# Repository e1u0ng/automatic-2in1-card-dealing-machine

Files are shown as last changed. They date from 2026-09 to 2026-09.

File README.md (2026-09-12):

# 🃏 Automated ESP32 Card Shuffler & Launcher

An ESP32-powered machine that shuffles and passes cards to players with an interactive menu screen for customized game settings. 

## 🔄 V1 Assembly Changes (9/11/26)
* **Improved Shuffler Performance:** 
  * Increased deck space to prevent overflowing cards going near spinning wheels
  * Covered more gap in the inner walls to prevent lodged cards
* **Redesigned Dispenser:** 
  * Added an angled ramp in the deck compartment to guarantee contact with the wheels (aimed to combat inconsistency with bent cards)
  * Switched to compound gear train for compactness and its gear ratio from 1:6.5 to 1:10 to make up for smaller wheel diameter
  * Switched to 32 mm diameter gecko wheels for compactness
* **Code Layout Redesign:** 
  * Implemented header files and source files for each subsystem (dispenser, shuffler, turret, menu) containing initialization and action functions
  * Used a separate command system file to translate inputs (button encoders) into outputs from the shuffler, dispenser, turret, and menu screen 
  * Utilized the FreeRTOS task system to run multiple tasks at the same time

## 🚀 Next Steps
* **Github Files:**
  * Upload current bill of materials for V1 (BOM)
  * Update specifications checklist for V1
* **Power Management:**
  * Assemble the 12.6V 3S Li-ion battery pack with integrated BMS protection.
  * Wire an SPDT charging/main power selector switch to safely isolate the load during recharges.
  * Implement an ESP32 ADC resistor divider circuit and software-based low-voltage shutdown routine before BMS cutoff.
* **Turret Redesign:**
  * Switch to a smaller brushed DC motor and separate absolute magnetic encoder
  * Refine ESP-IDF PID loop control for new turret setup and implement exact player-angle targeting using an absolute encoder
* **PCB Design:**
  * Design PCB to hold the ESP32 microcontroller, shutdown circuit, and power lines for compactness
* **Sensors Implementations:**
  * Integrate IR sensors for directional card delivery detection and optional distance sensors for adaptive shuffle timing.
* **Enclosure Design:**
  * Use Fusion360 to design a container to hold the subsystems together for a finished look

## 📂 Repository Structure
* `docs/` — Design sketches, calculations, and proof-of-concept testing logs.
* `hardware/` — Circuit diagrams, power schematics, and 3D STL/STEP models.
* `main/` — ESP32 C++ source code and all test codes

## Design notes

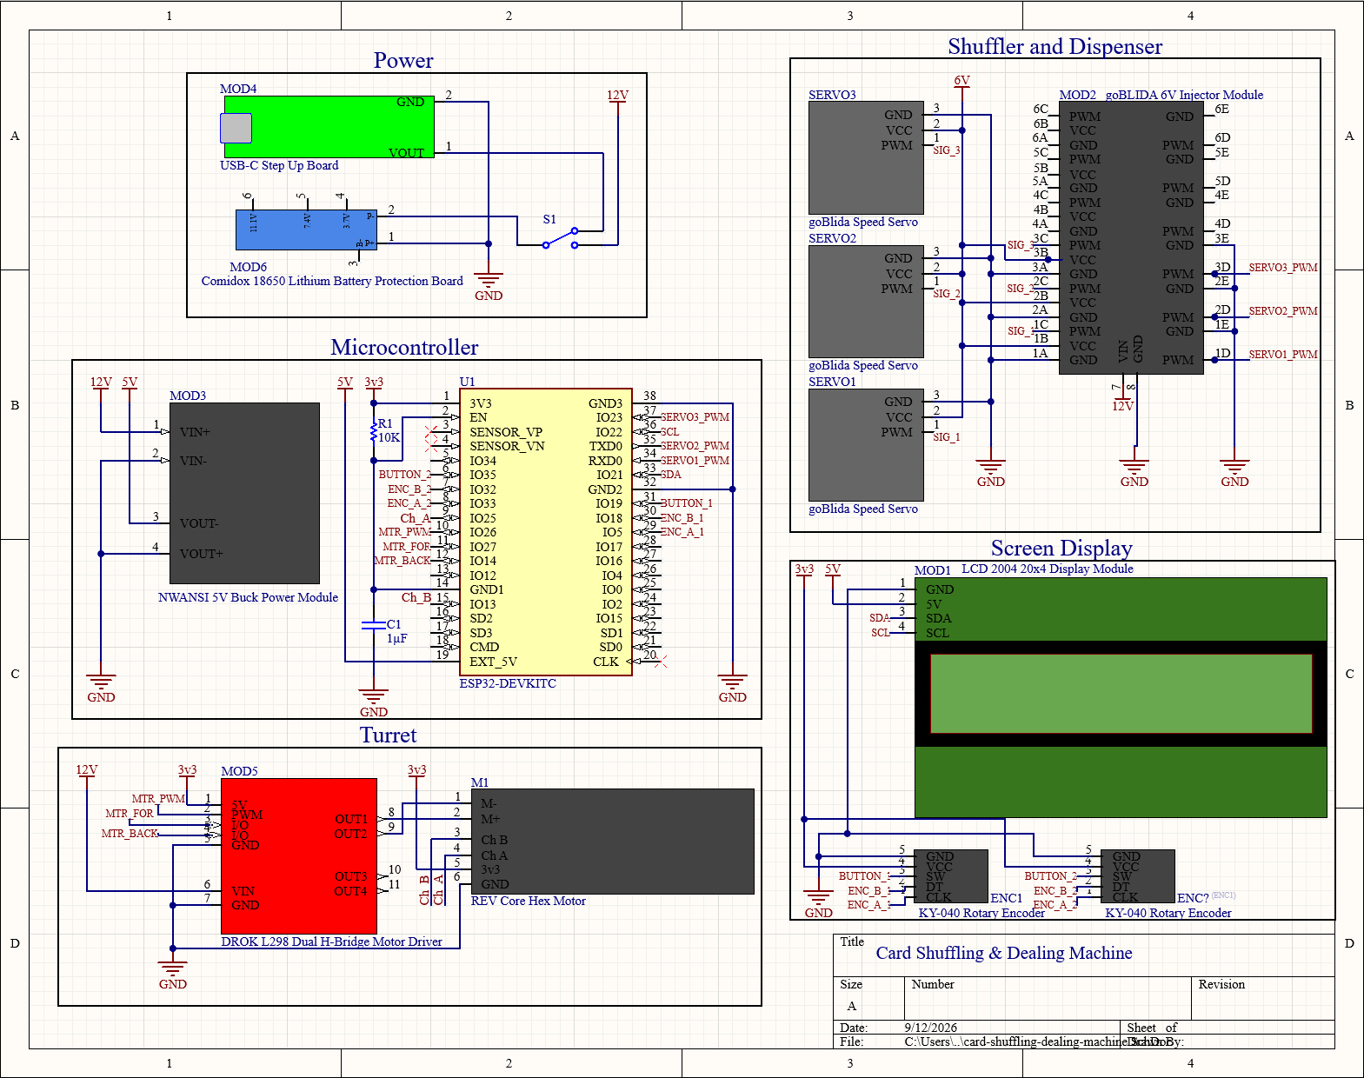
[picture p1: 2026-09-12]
hardware/schematics/card-shuffling-dealing-machine-schematic.png

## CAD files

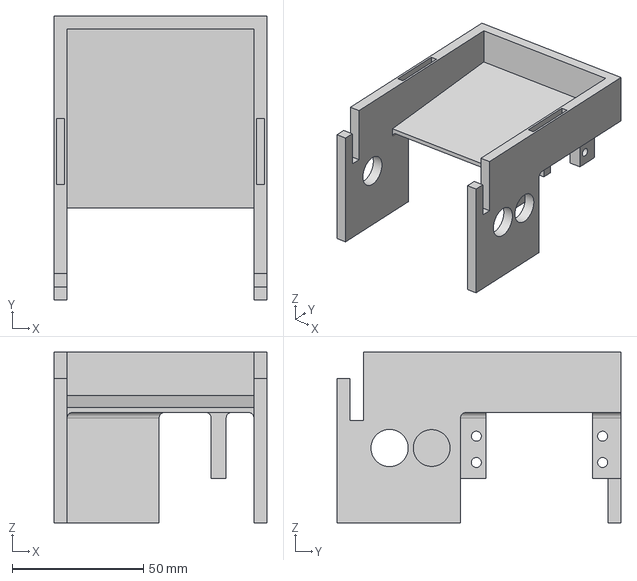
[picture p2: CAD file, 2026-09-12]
hardware/3d_models/step/dispenser/card-dispenser-chassis.step
81.0 x 108.0 x 65.0 mm

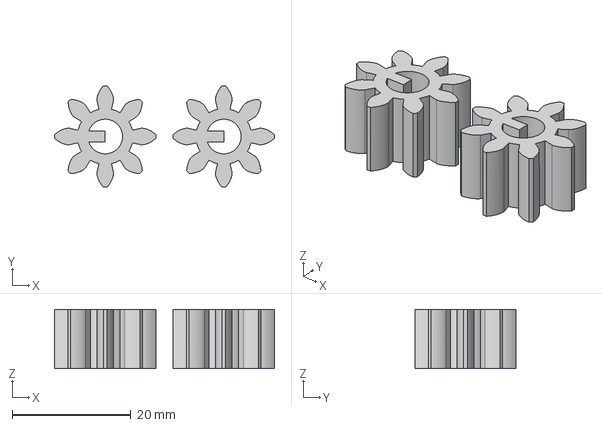
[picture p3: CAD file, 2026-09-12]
hardware/3d_models/step/shuffler/card-shuffler-driven-gears.step
37.1 x 17.1 x 10.0 mm

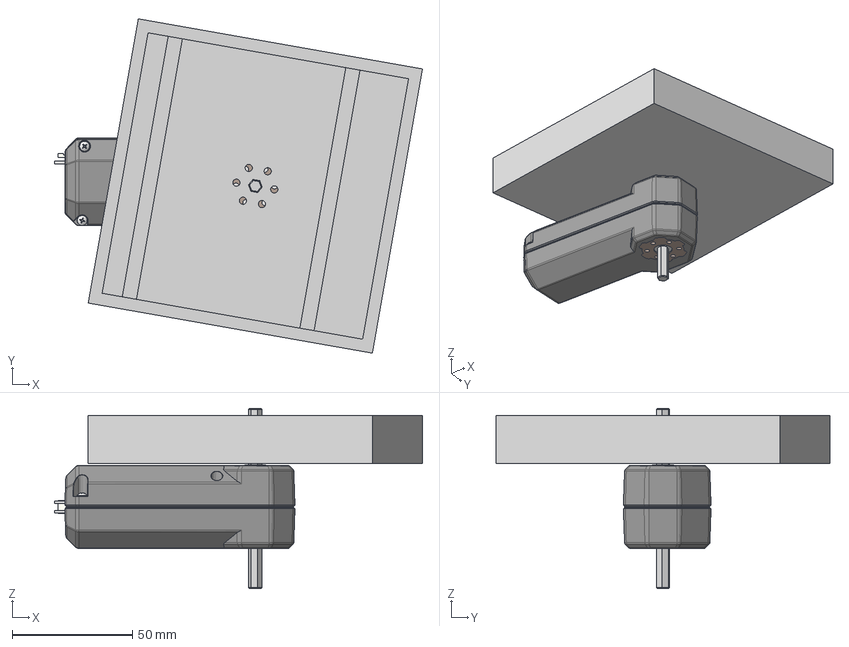
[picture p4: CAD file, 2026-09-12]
hardware/3d_models/step/turret/card-turret.step
153.0 x 139.0 x 75.0 mm

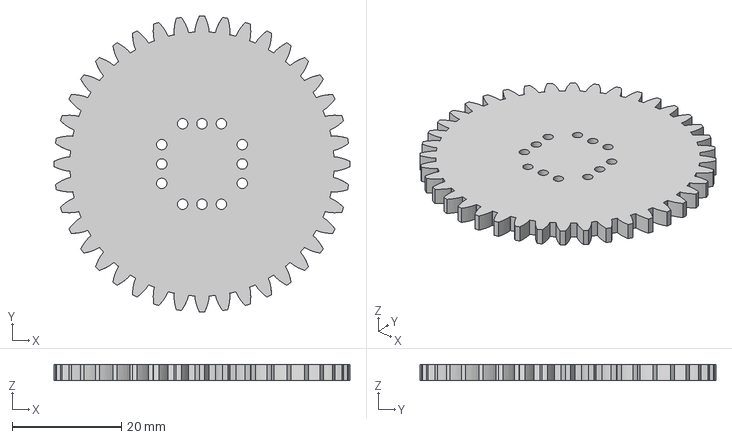
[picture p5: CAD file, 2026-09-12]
hardware/3d_models/step/dispenser/dispenser-driver-gear.step
54.2 x 54.2 x 3.00 mm

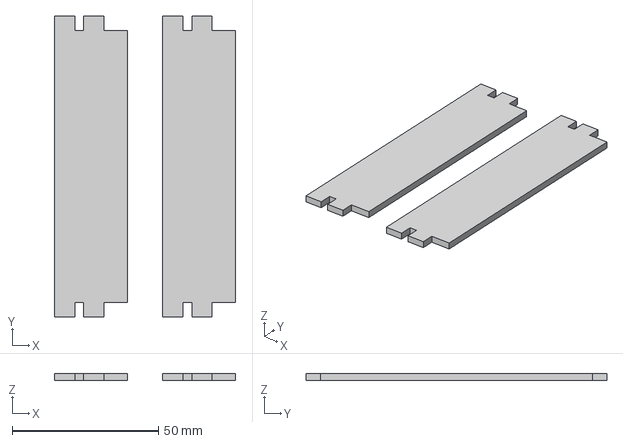
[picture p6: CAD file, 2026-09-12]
hardware/3d_models/step/shuffler/card-shuffler-platforms.step
62.0 x 103.0 x 2.50 mm

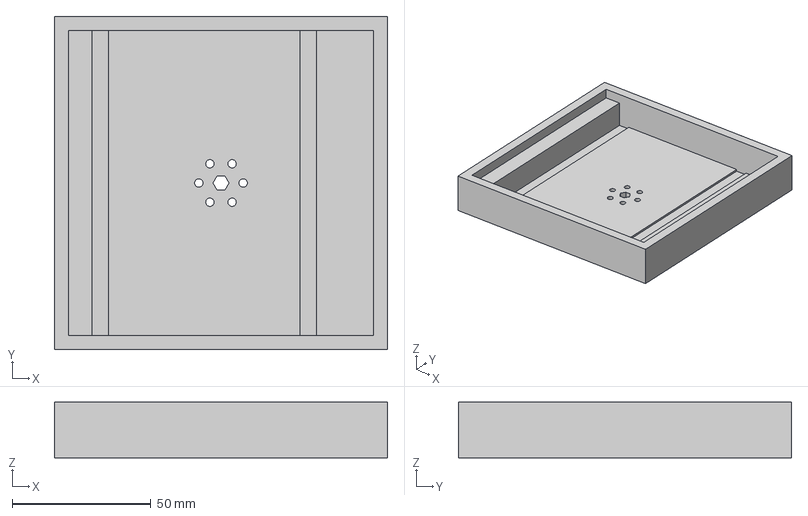
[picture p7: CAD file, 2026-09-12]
hardware/3d_models/step/turret/card-turret-platform.step
120.0 x 120.0 x 20.0 mm

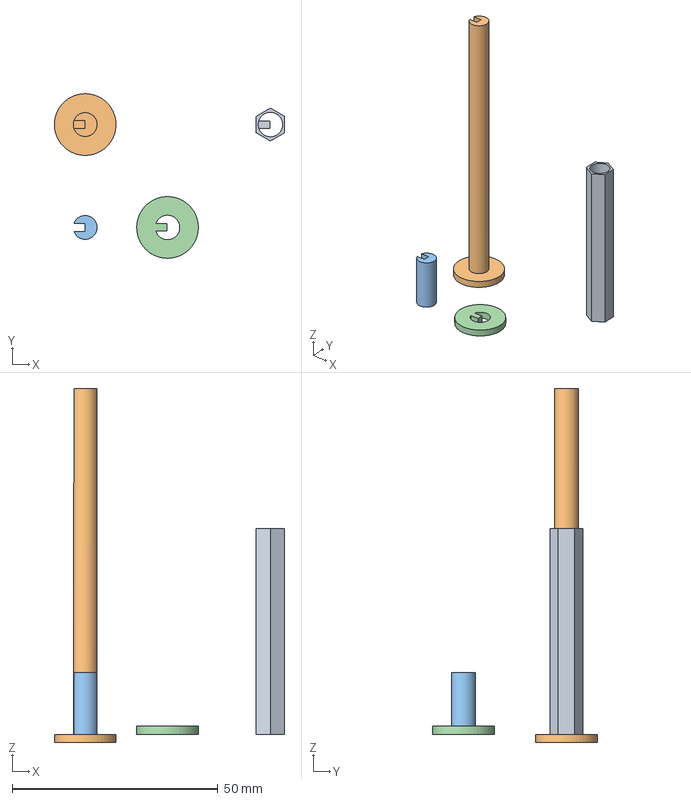
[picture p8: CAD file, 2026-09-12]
hardware/3d_models/step/dispenser/card-dispenser-shaft.step
56.0 x 40.0 x 86.0 mm

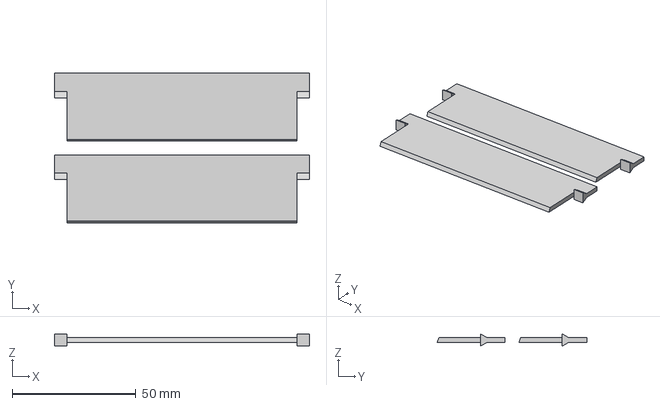
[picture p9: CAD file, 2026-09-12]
hardware/3d_models/step/shuffler/card-shuffler-gates.step
103.0 x 60.5 x 5.00 mm

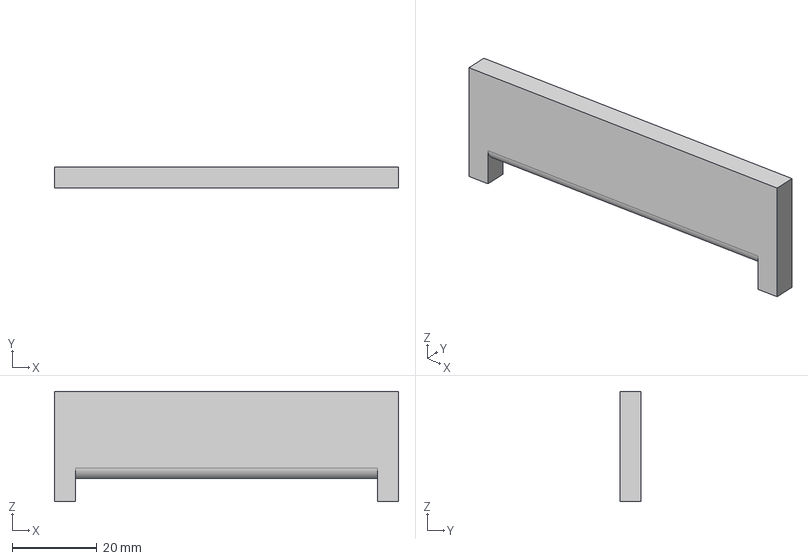
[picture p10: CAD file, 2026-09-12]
hardware/3d_models/step/dispenser/dispenser-gate.step
81.0 x 5.00 x 26.0 mm

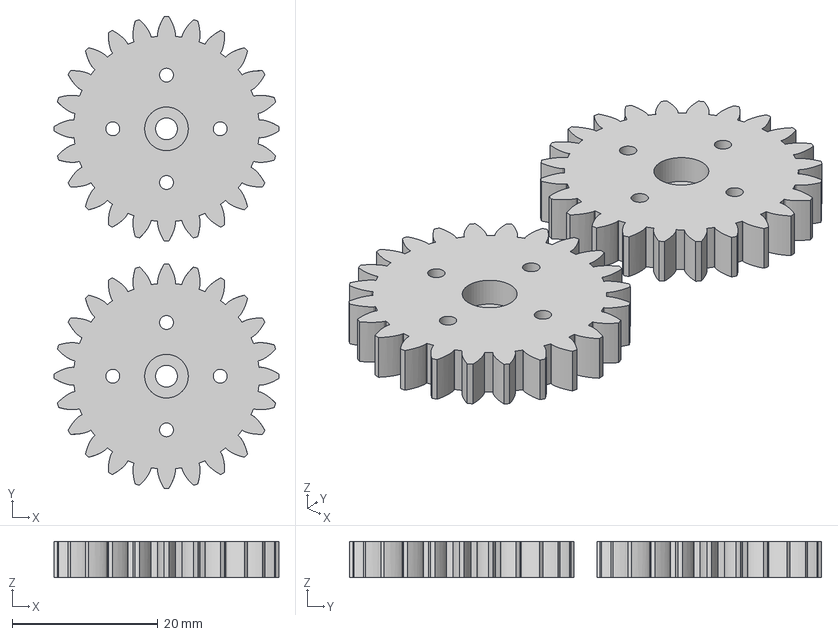
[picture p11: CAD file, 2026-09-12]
hardware/3d_models/step/shuffler/card-shuffler-driver-gears.step
30.9 x 64.9 x 5.00 mm

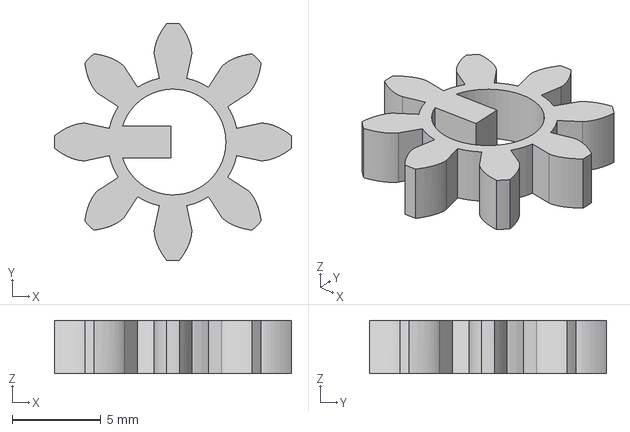
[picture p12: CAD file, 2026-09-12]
hardware/3d_models/step/dispenser/dispenser-driven-gear.step
13.3 x 13.3 x 3.00 mm

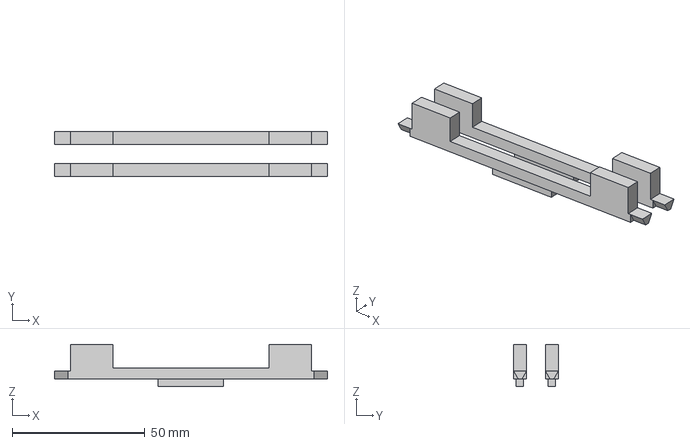
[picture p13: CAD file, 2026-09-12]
hardware/3d_models/step/shuffler/card-shuffler-inner-walls.step
103.0 x 17.0 x 16.0 mm

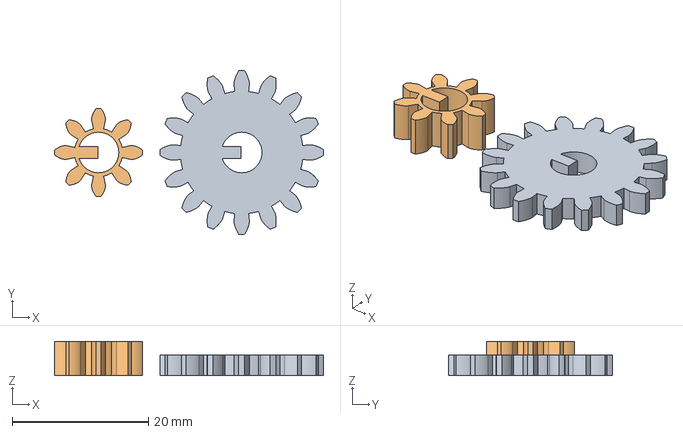
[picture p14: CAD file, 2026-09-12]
hardware/3d_models/step/dispenser/card-dispenser-middle-gears.step
39.5 x 24.0 x 5.00 mm

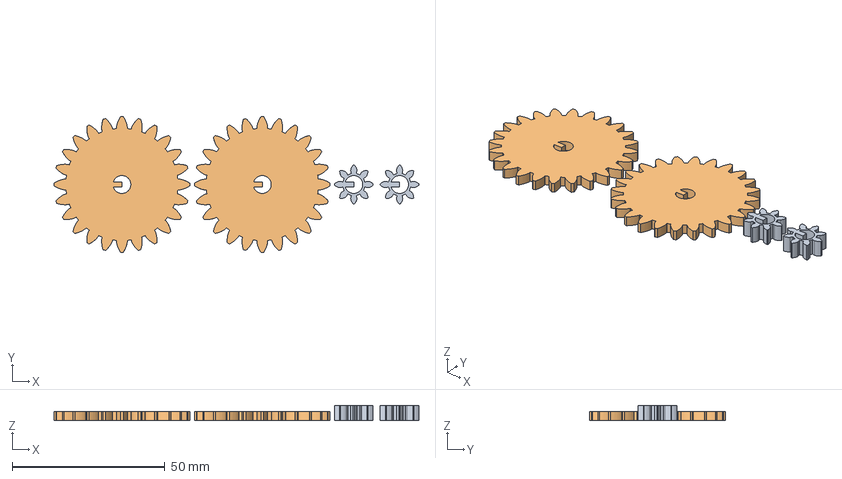
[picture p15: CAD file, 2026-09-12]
hardware/3d_models/step/shuffler/card-shuffler-middle-gears.step
119.6 x 44.5 x 5.00 mm

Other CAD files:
hardware/3d_models/step/dispenser/card-dispenser.step
hardware/3d_models/step/shuffler/card-shuffler-side-plates.step
hardware/3d_models/step/shuffler/card-shuffler-wheels-and-shaft.step
hardware/3d_models/step/shuffler/card-shuffler.step
hardware/3d_models/source/dispenser/card-dispenser.f3z
hardware/3d_models/source/shuffler/card-shuffler.f3z
hardware/3d_models/source/turret/card-turret.f3z
hardware/3d_models/stl/dispenser/card-dispenser-chassis.stl
hardware/3d_models/stl/dispenser/card-dispenser-middle-gears.stl
hardware/3d_models/stl/dispenser/card-dispenser-shaft.stl
hardware/3d_models/stl/dispenser/dispenser-driven-gear.stl
hardware/3d_models/stl/dispenser/dispenser-driver-gear.stl
hardware/3d_models/stl/dispenser/dispenser-gate.stl
hardware/3d_models/stl/shuffler/card-shuffler-driven-gears.stl
hardware/3d_models/stl/shuffler/card-shuffler-driver-gears.stl
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

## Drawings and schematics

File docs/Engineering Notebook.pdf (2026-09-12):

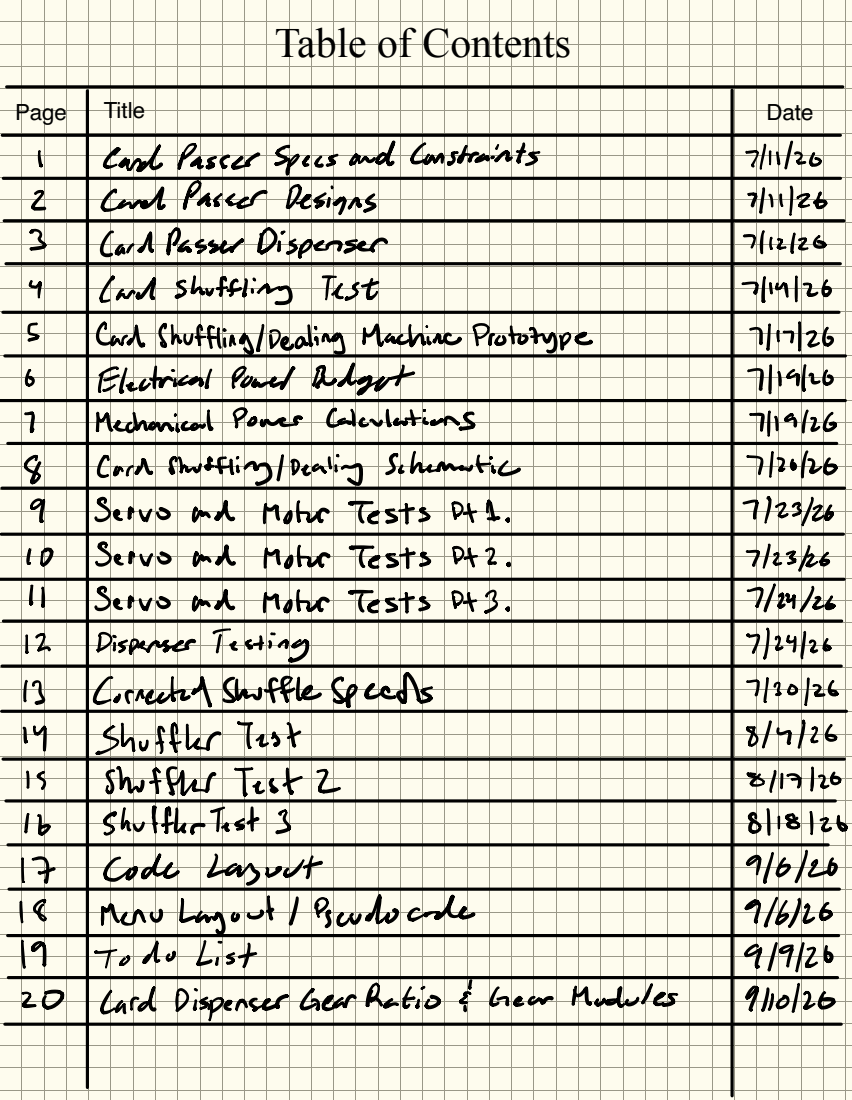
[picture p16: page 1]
Page; Title; Date

Table of Contents

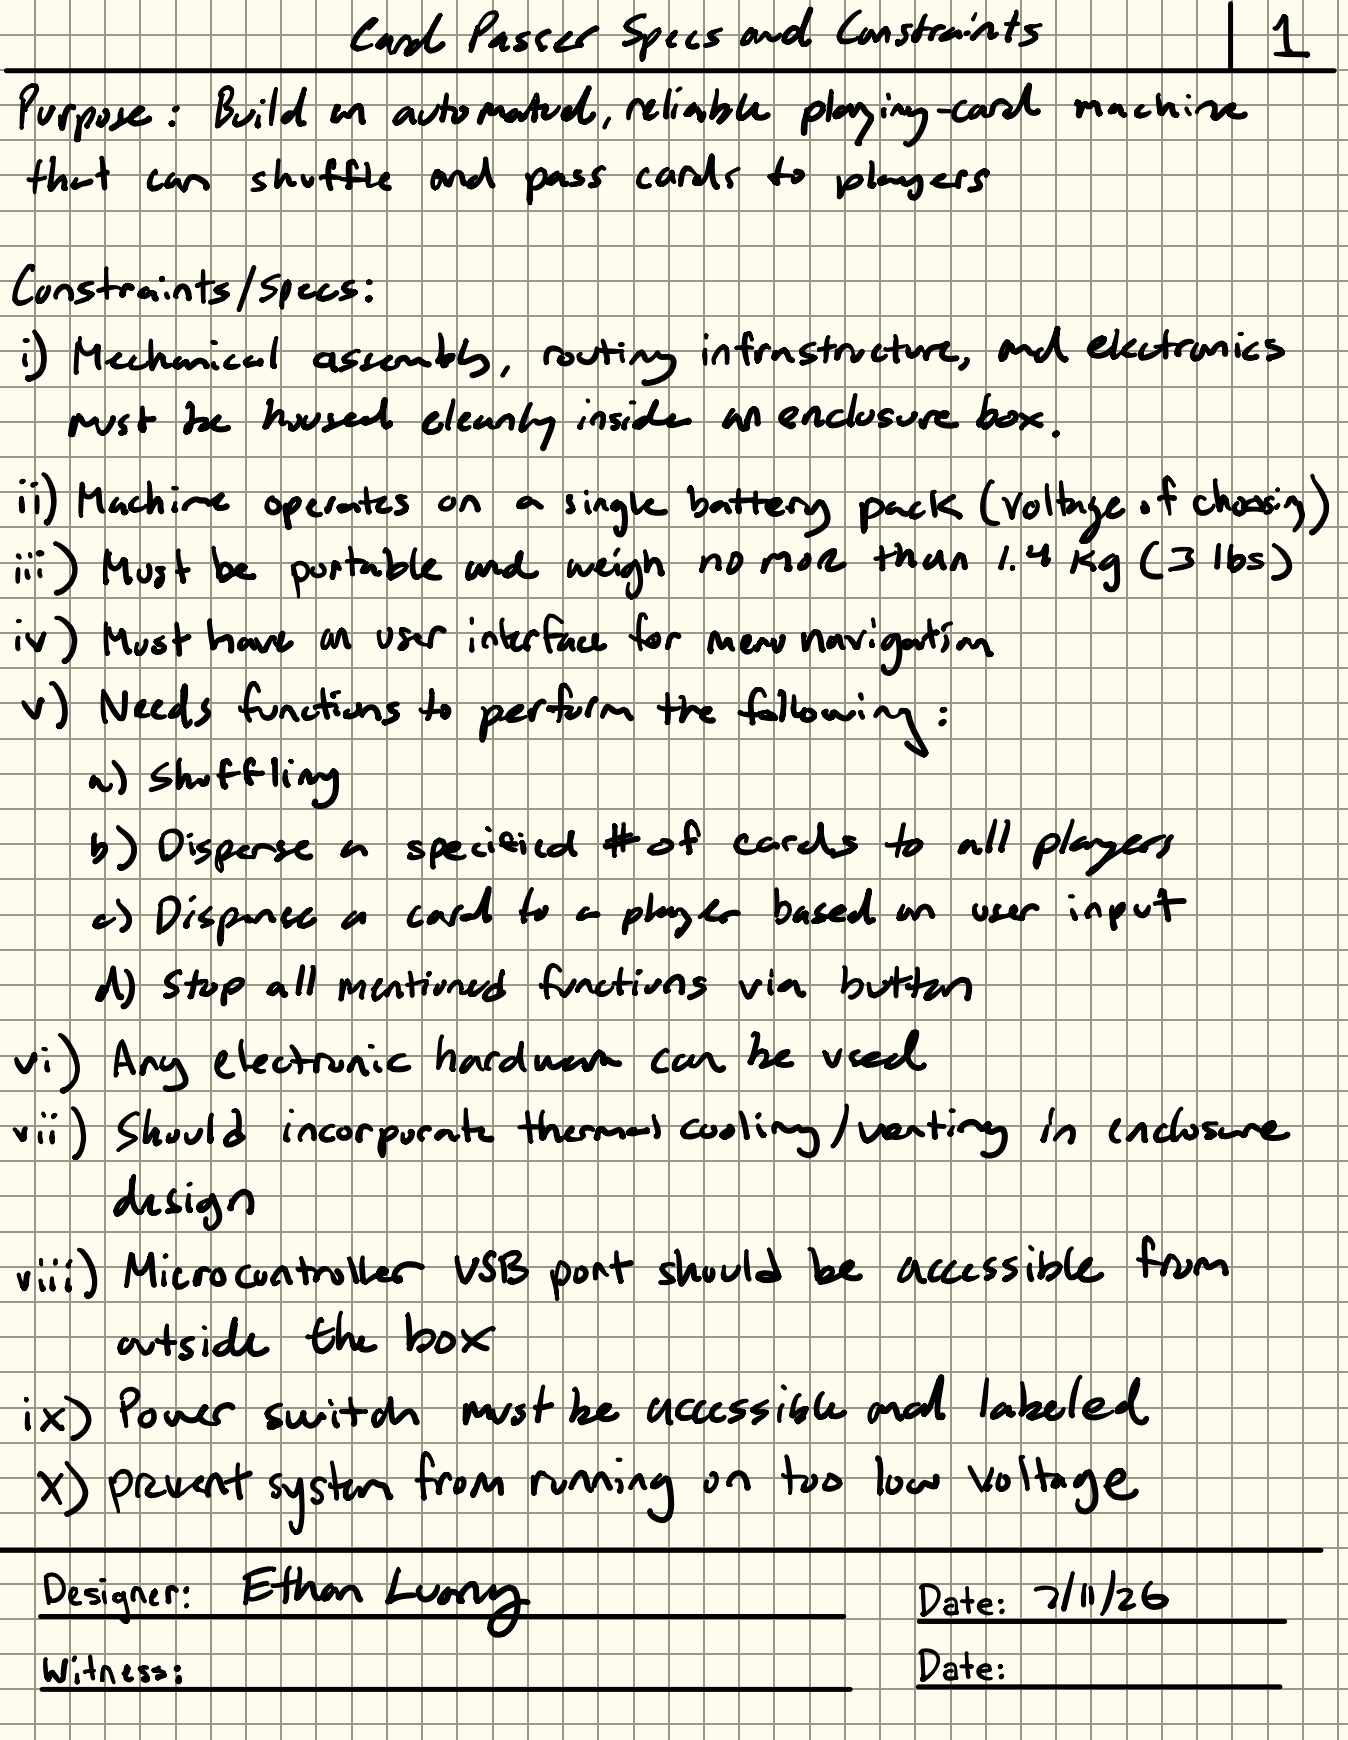
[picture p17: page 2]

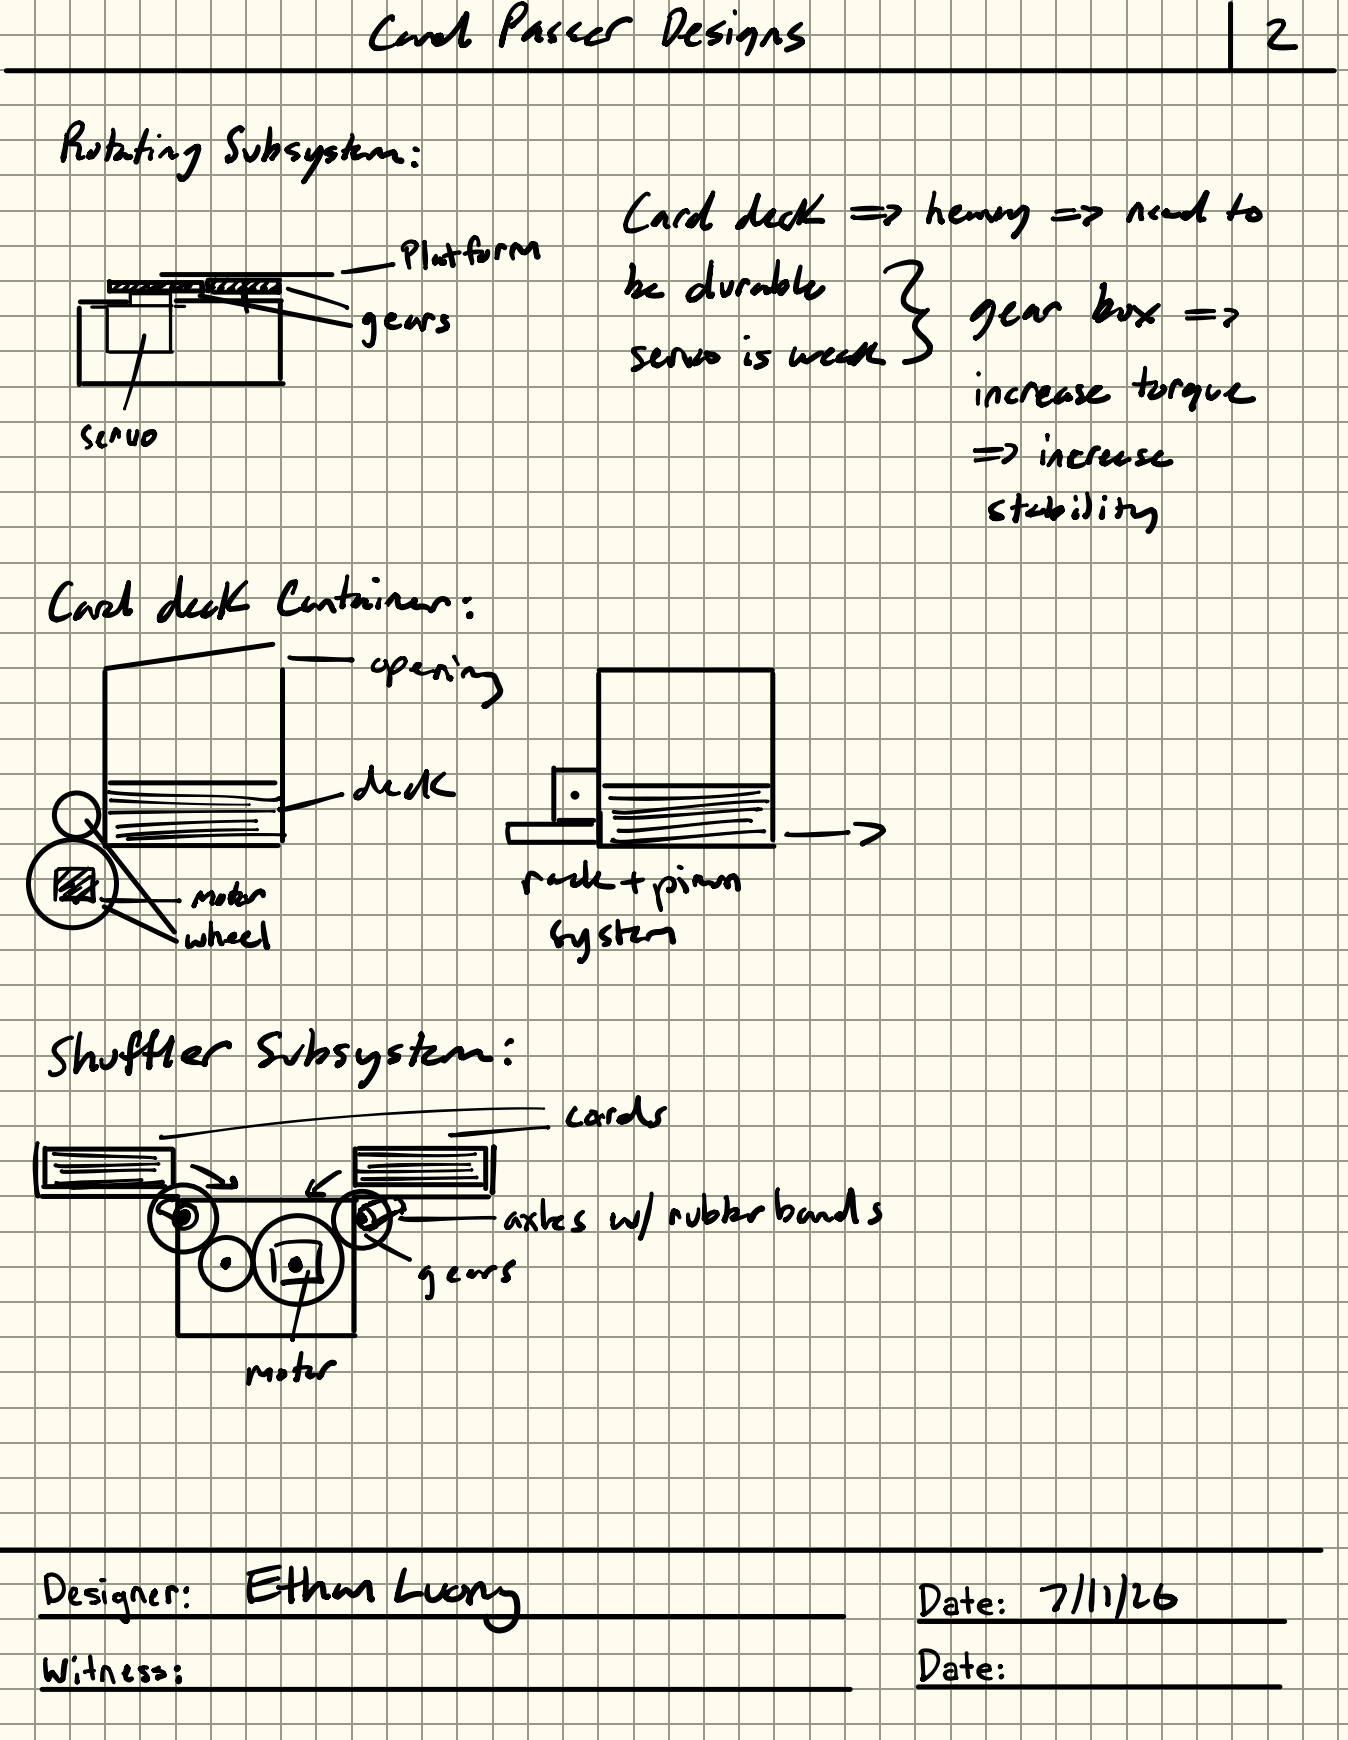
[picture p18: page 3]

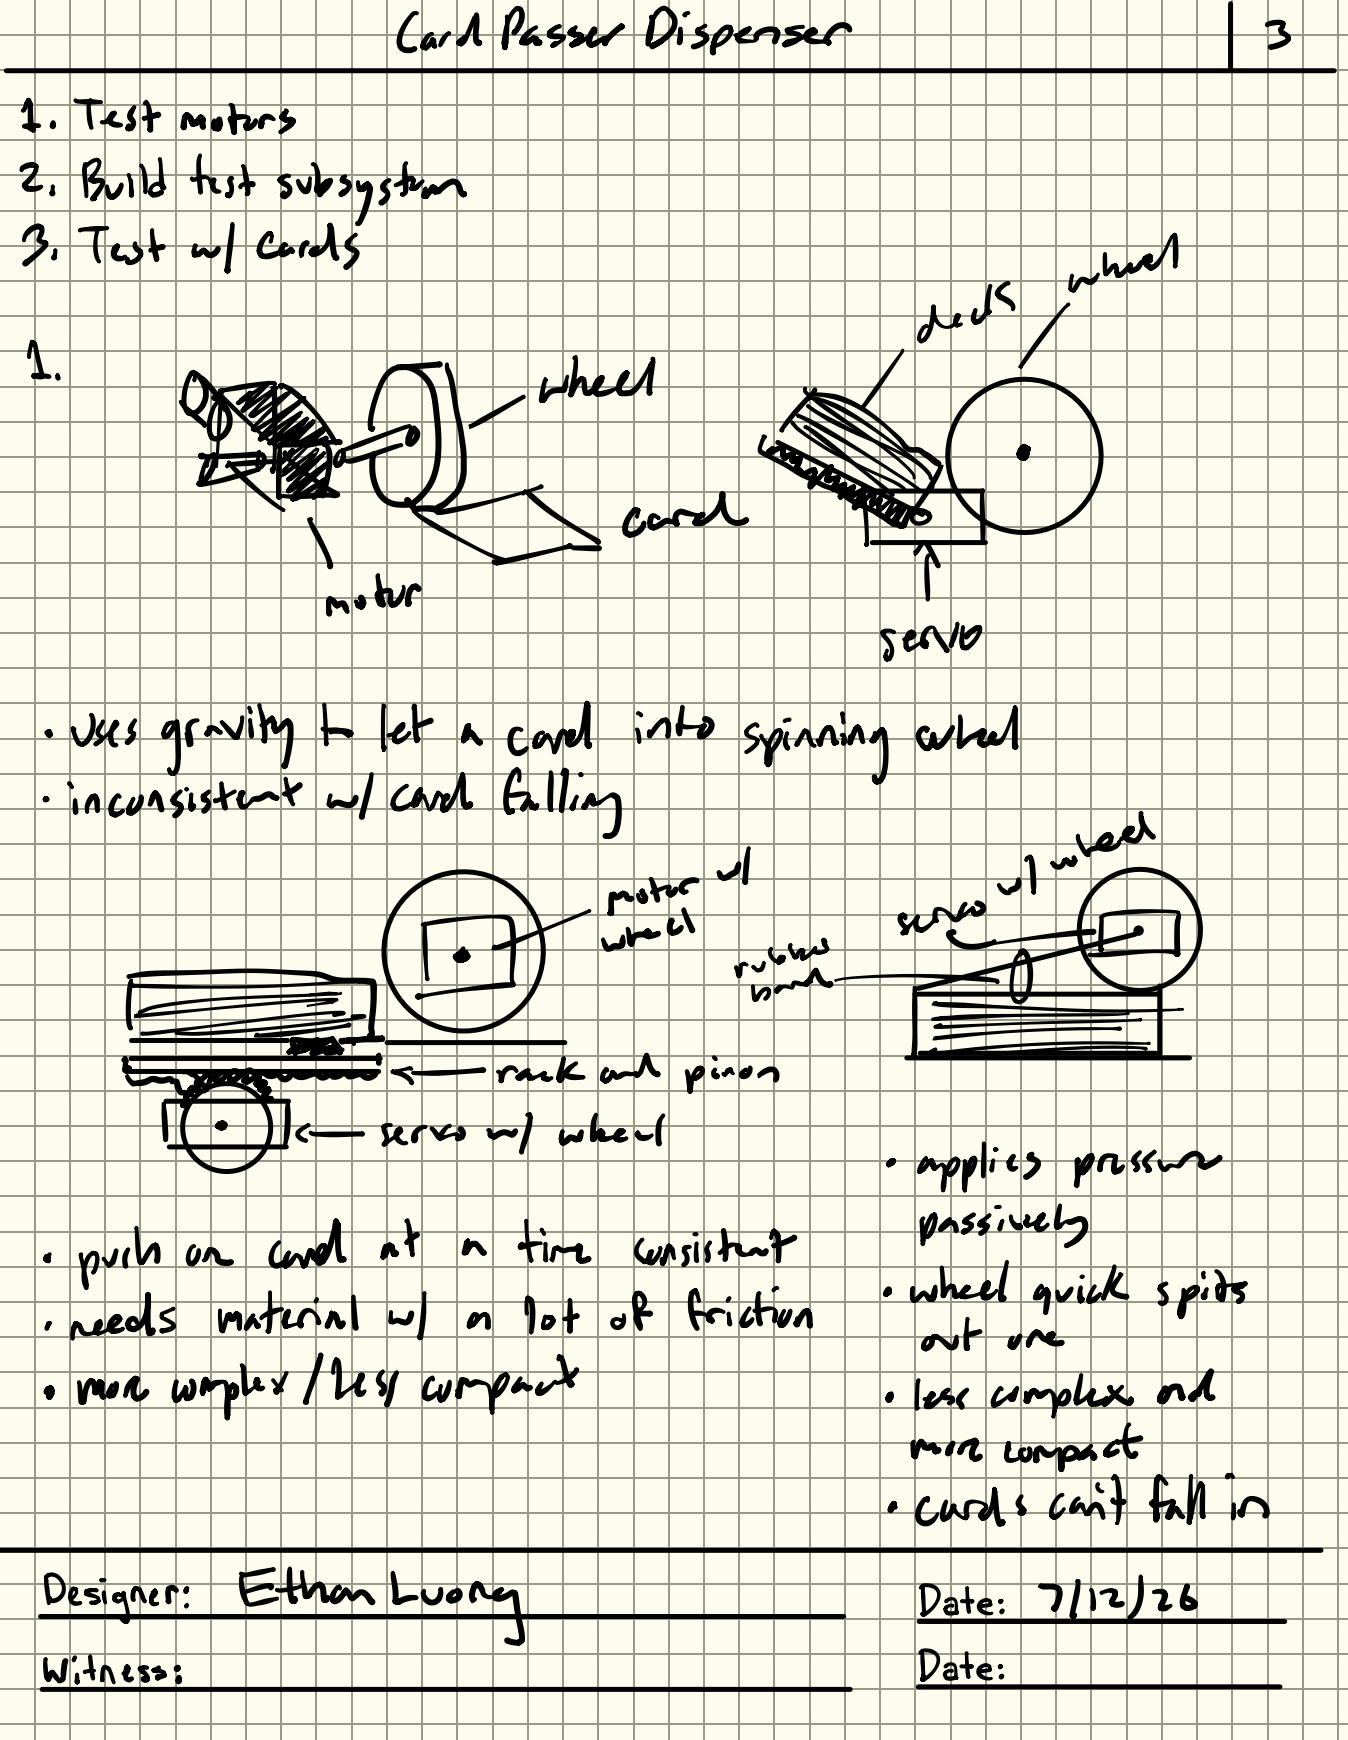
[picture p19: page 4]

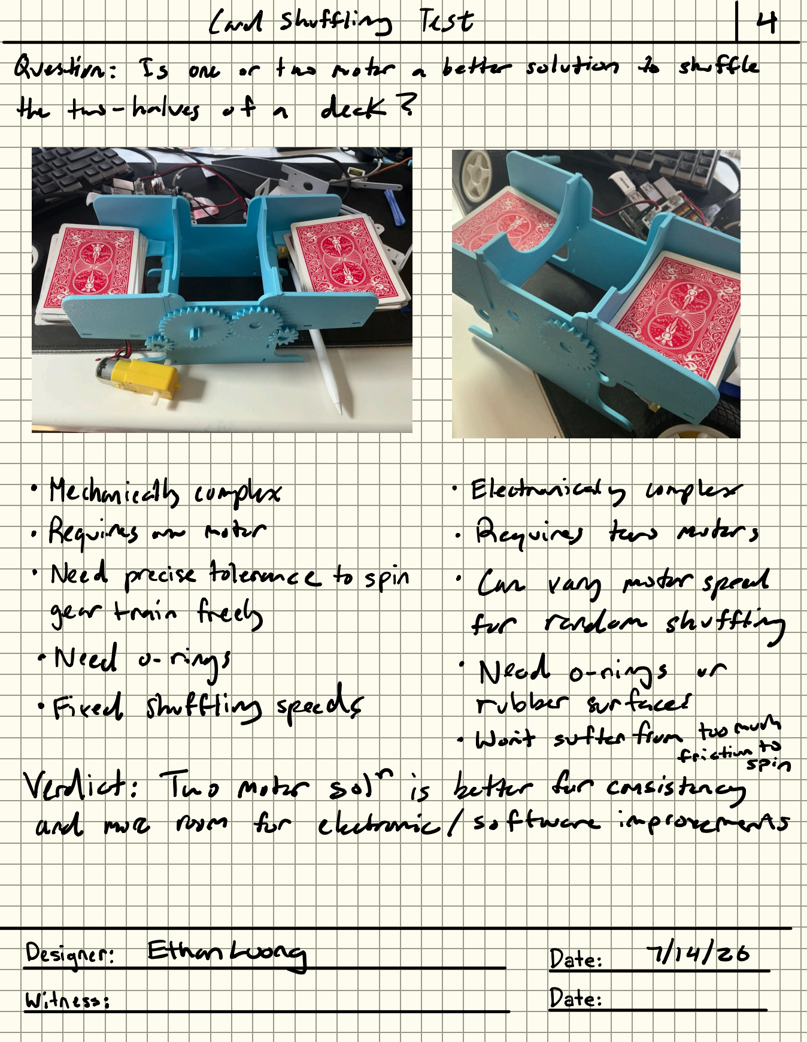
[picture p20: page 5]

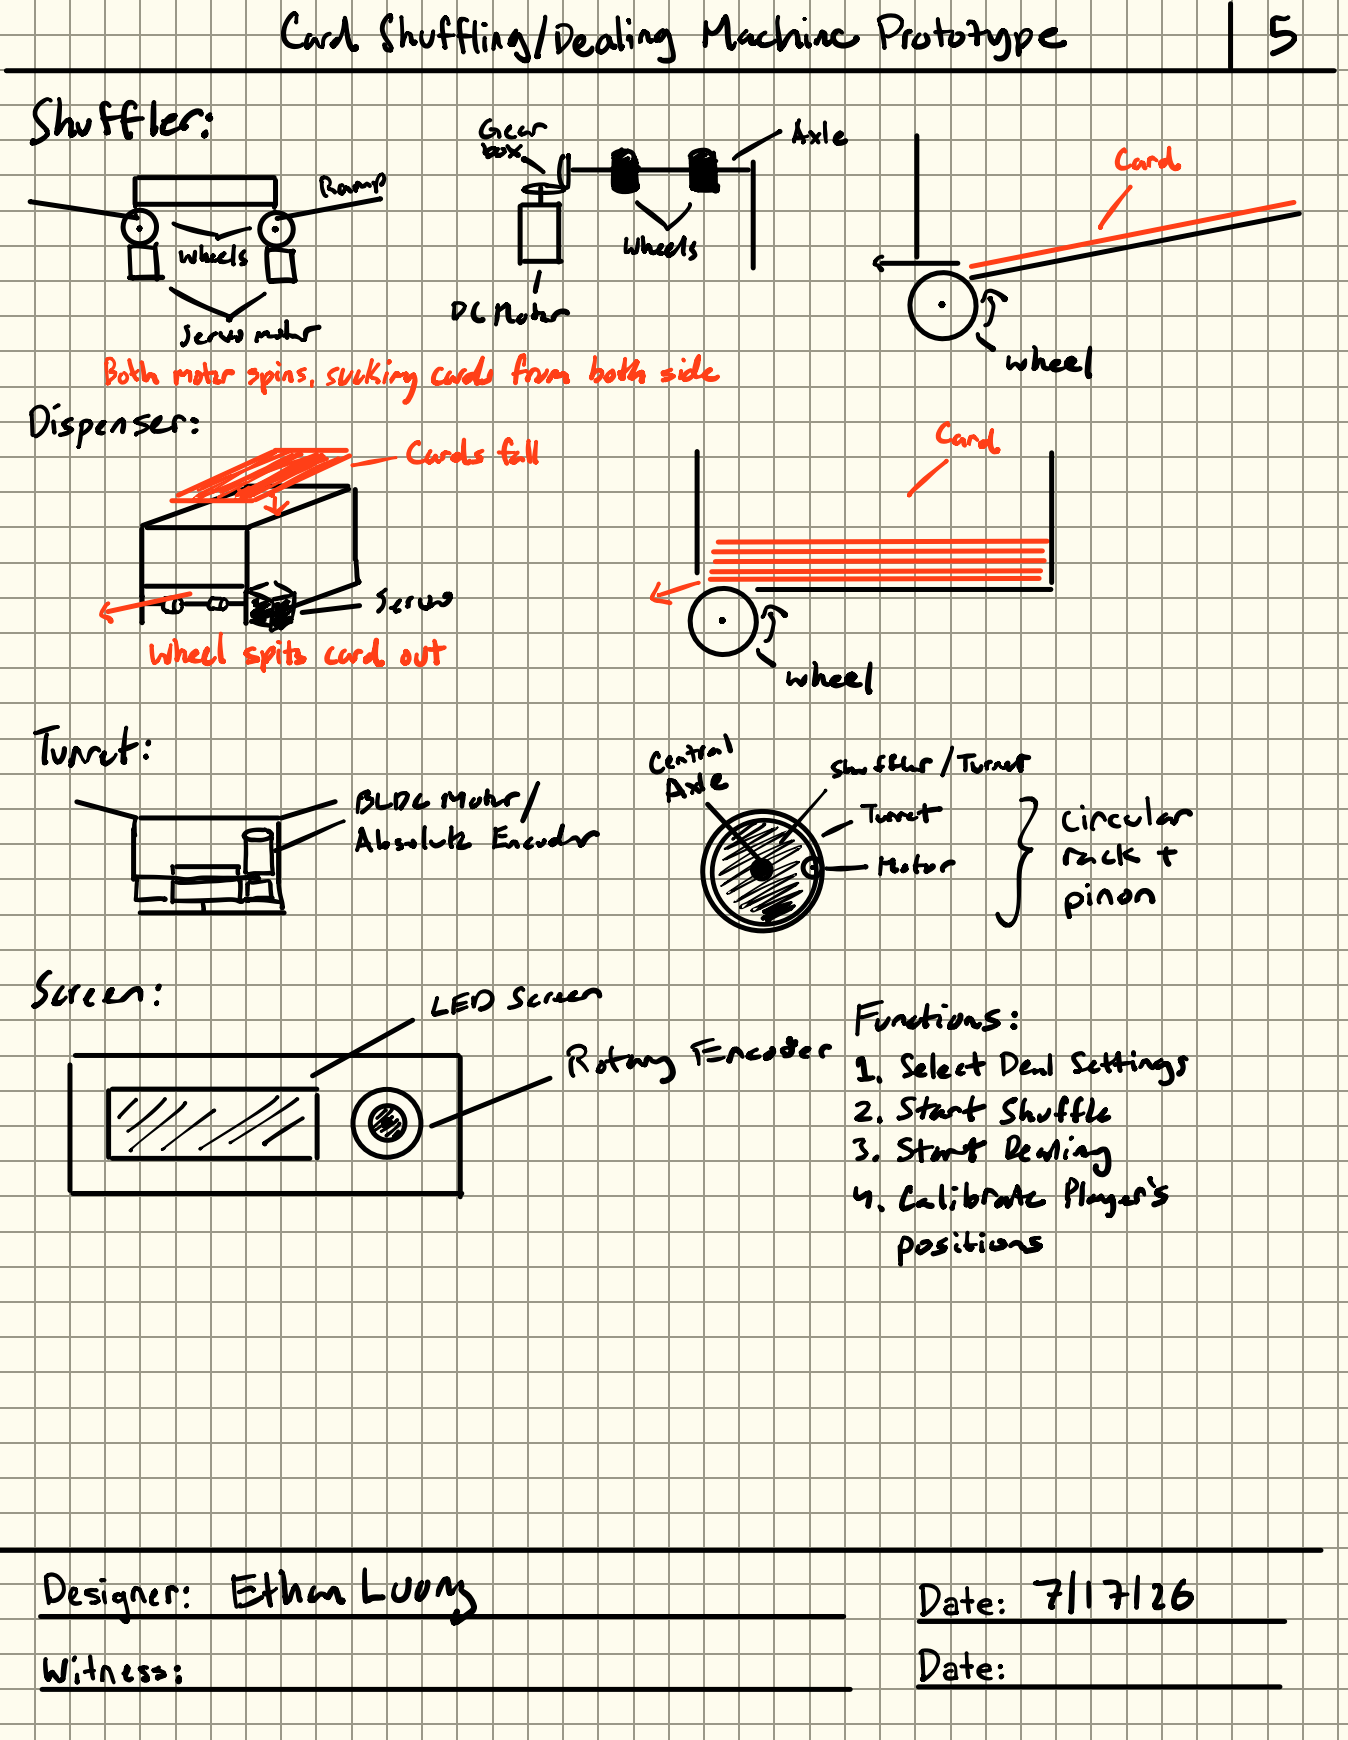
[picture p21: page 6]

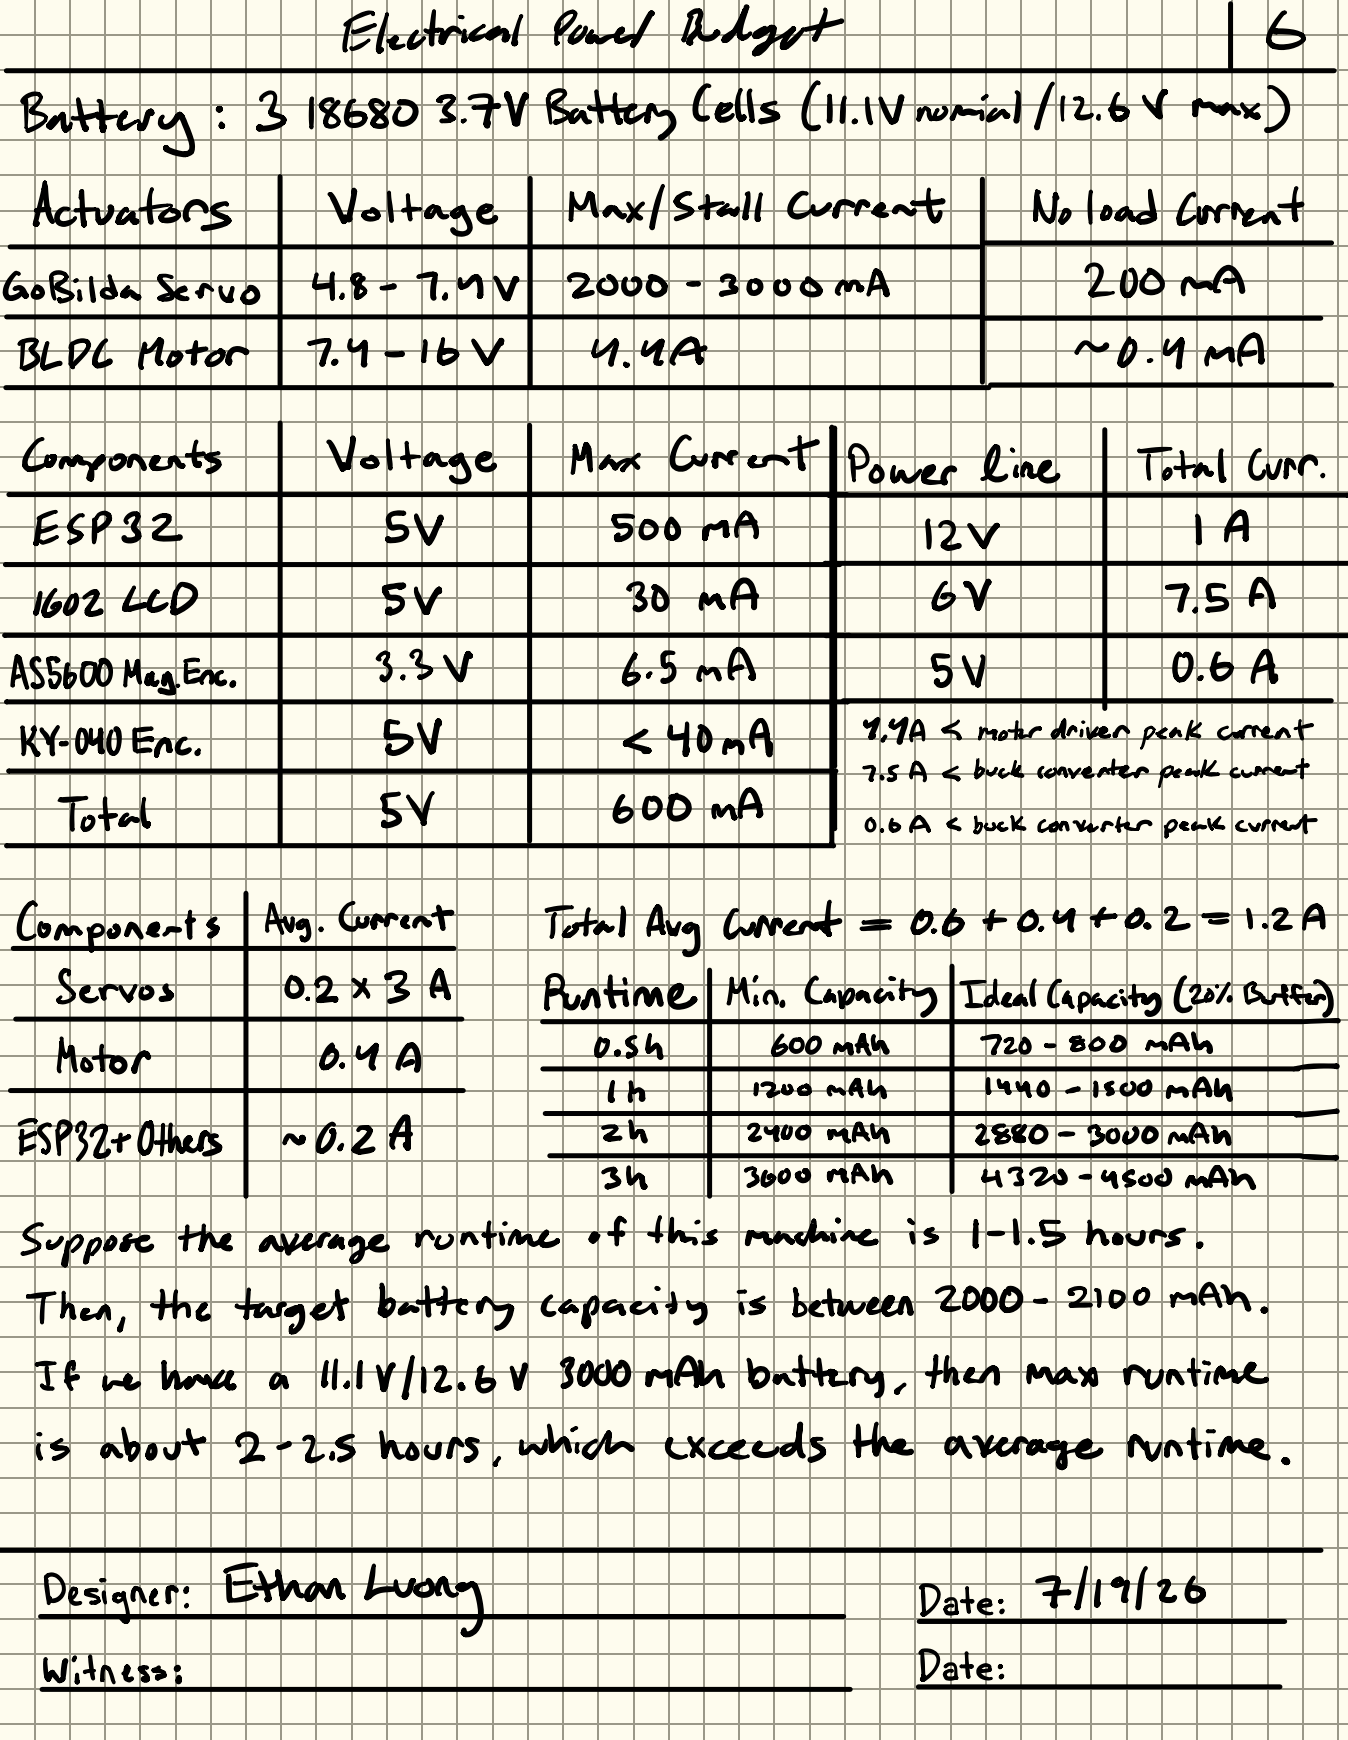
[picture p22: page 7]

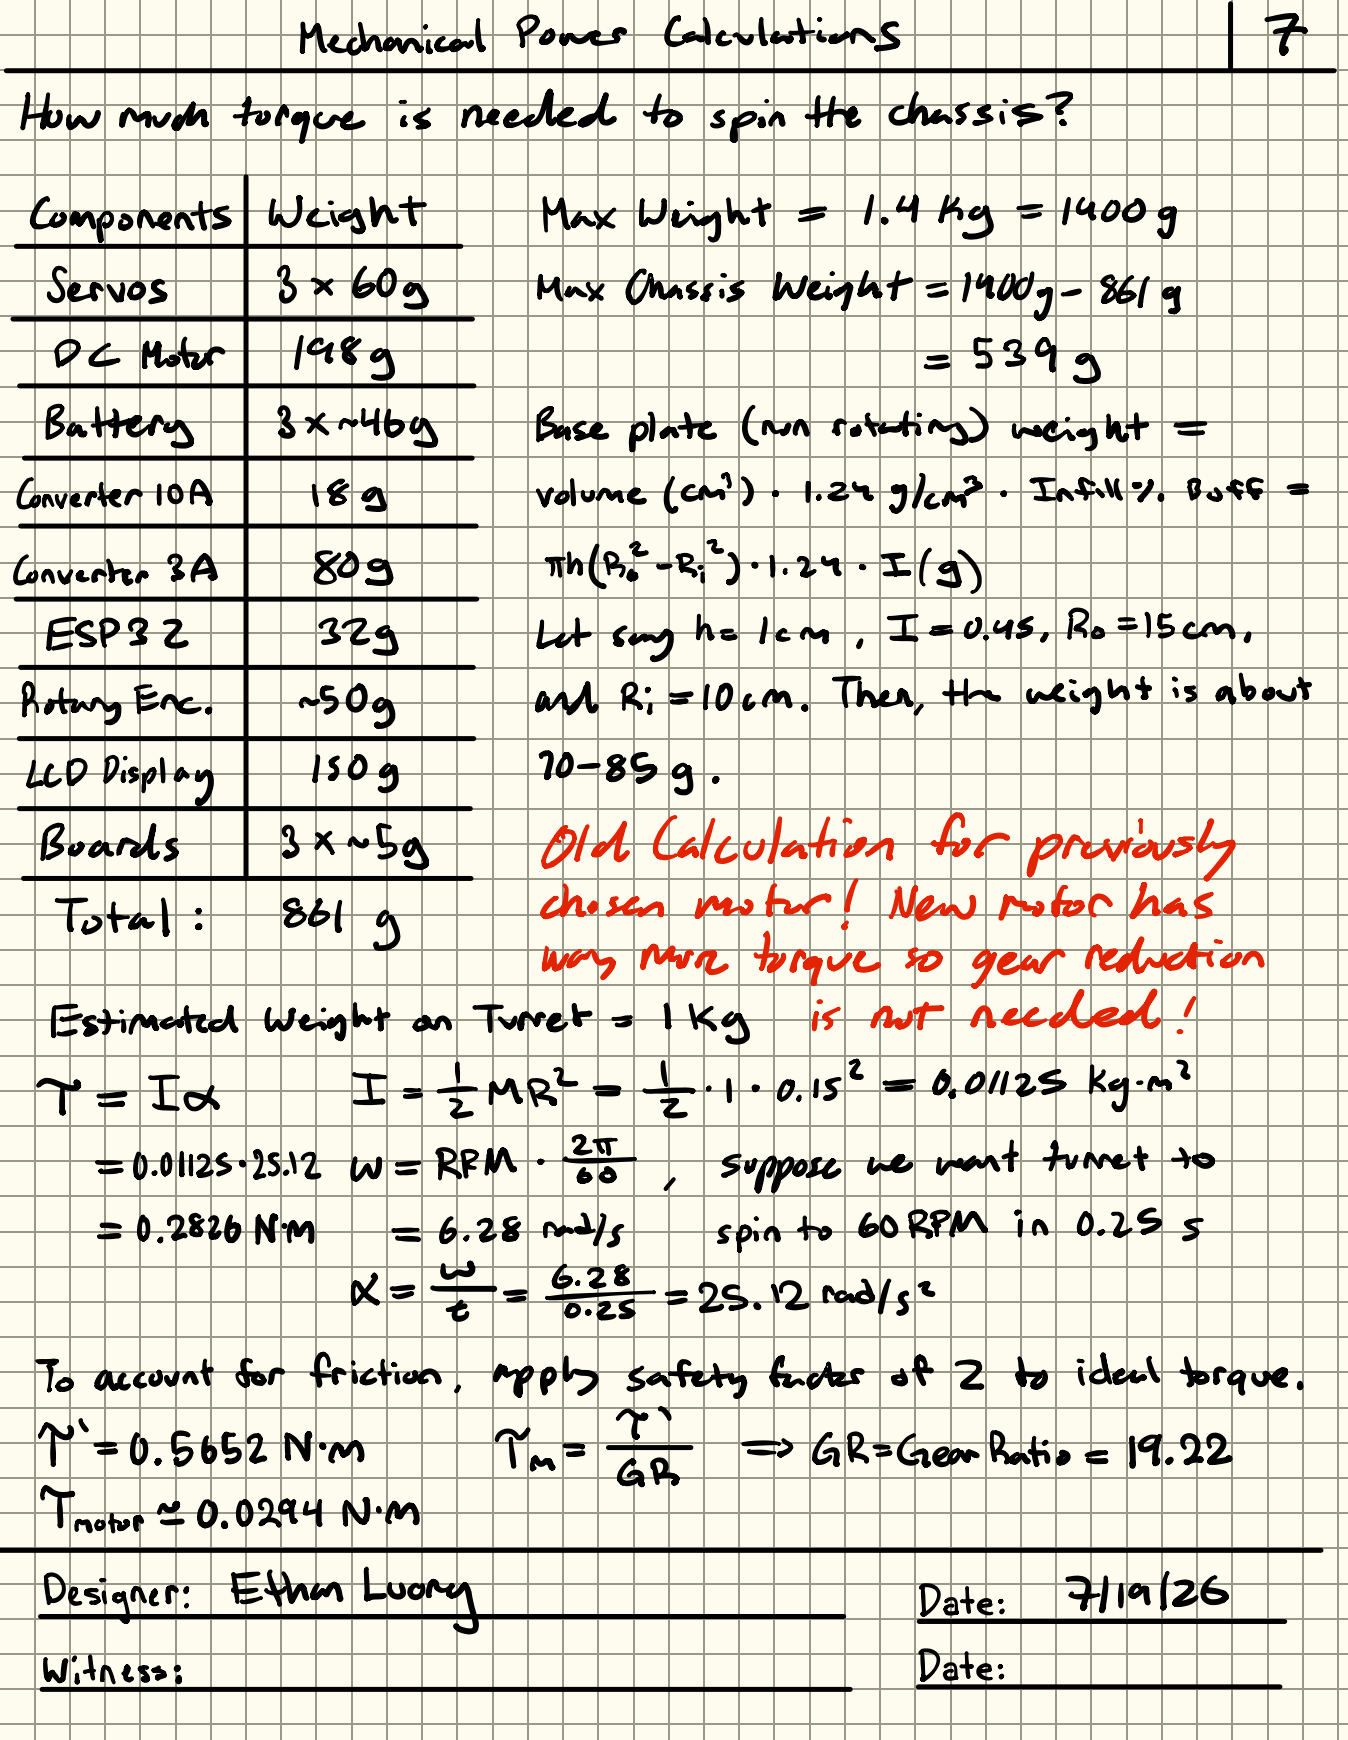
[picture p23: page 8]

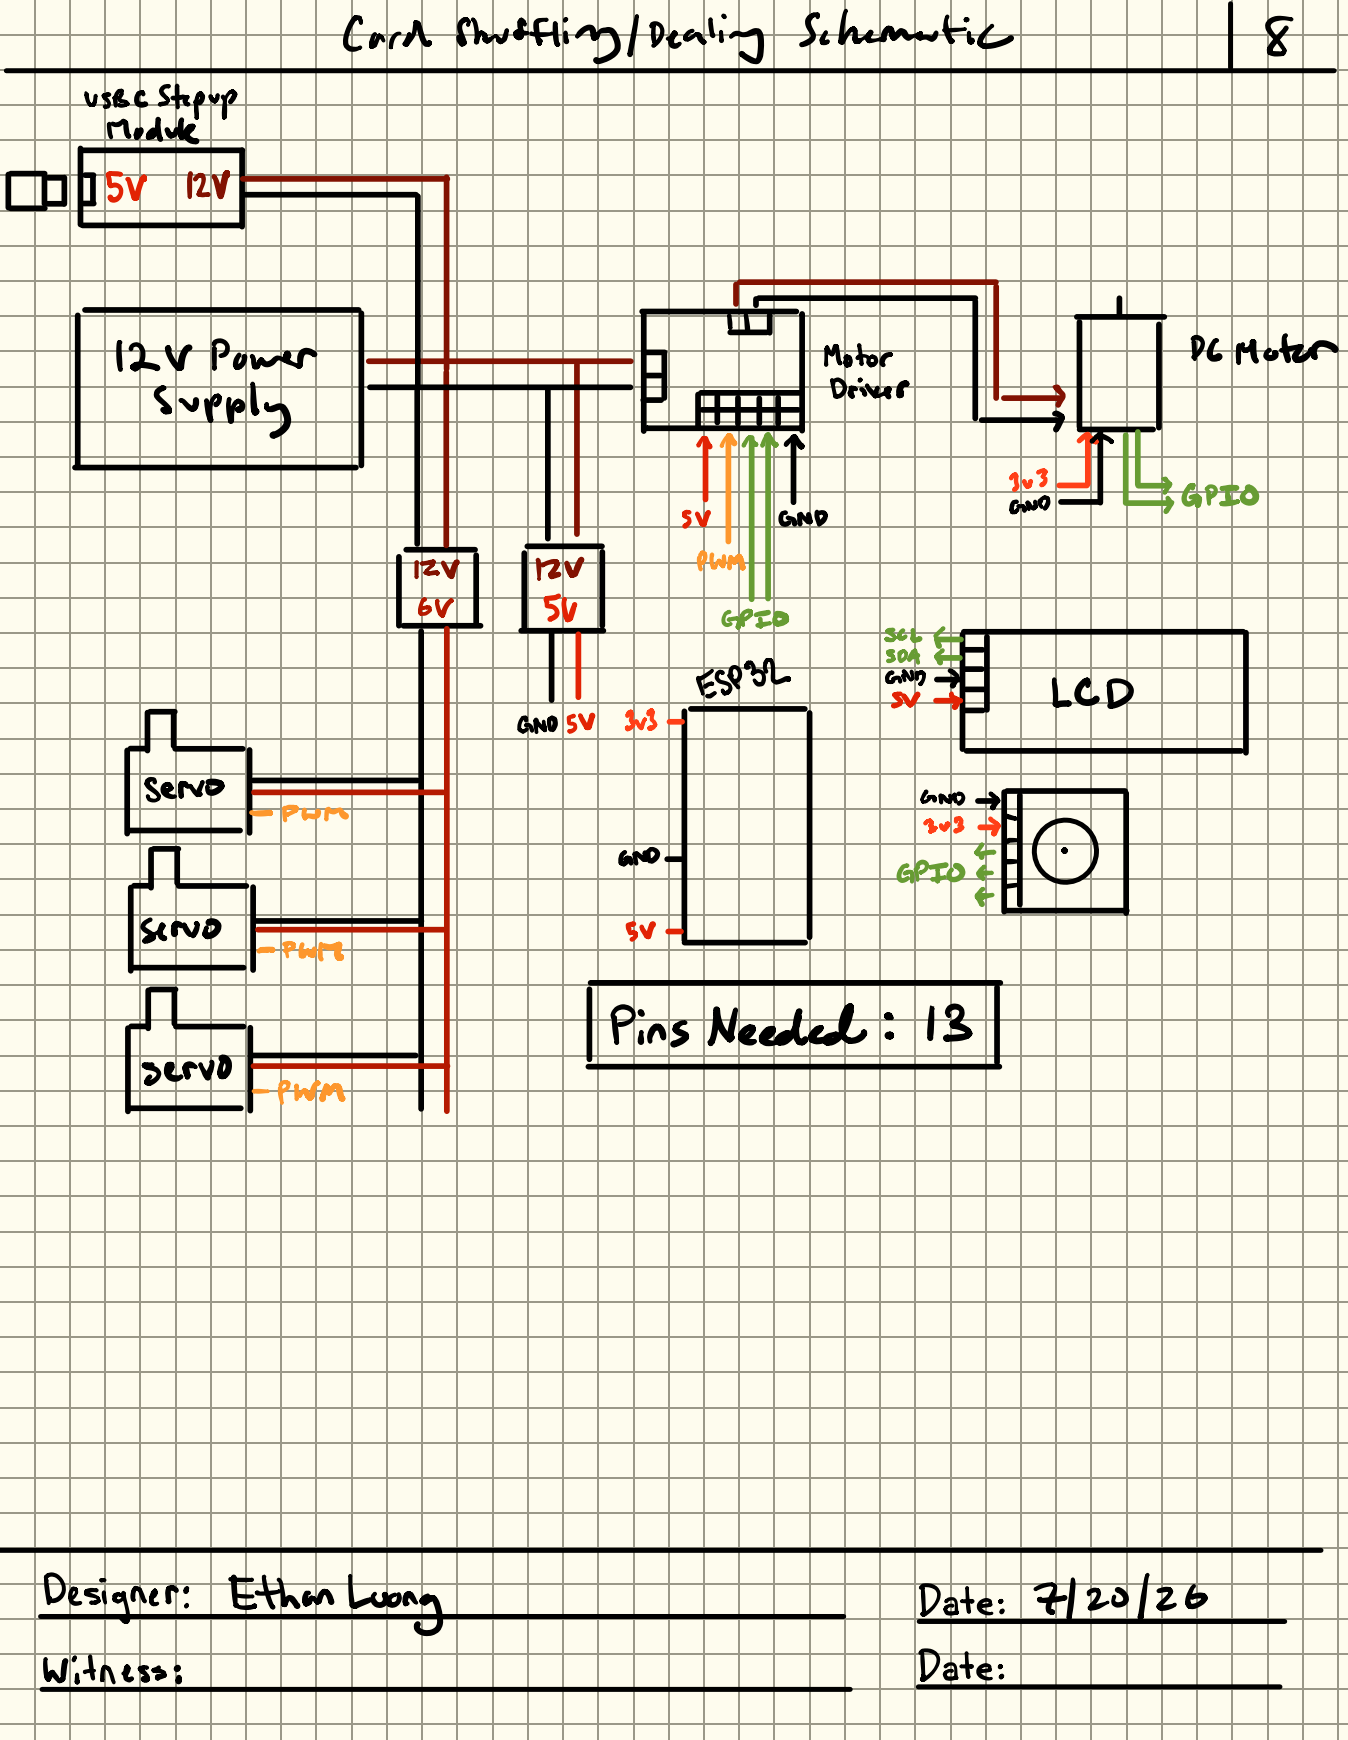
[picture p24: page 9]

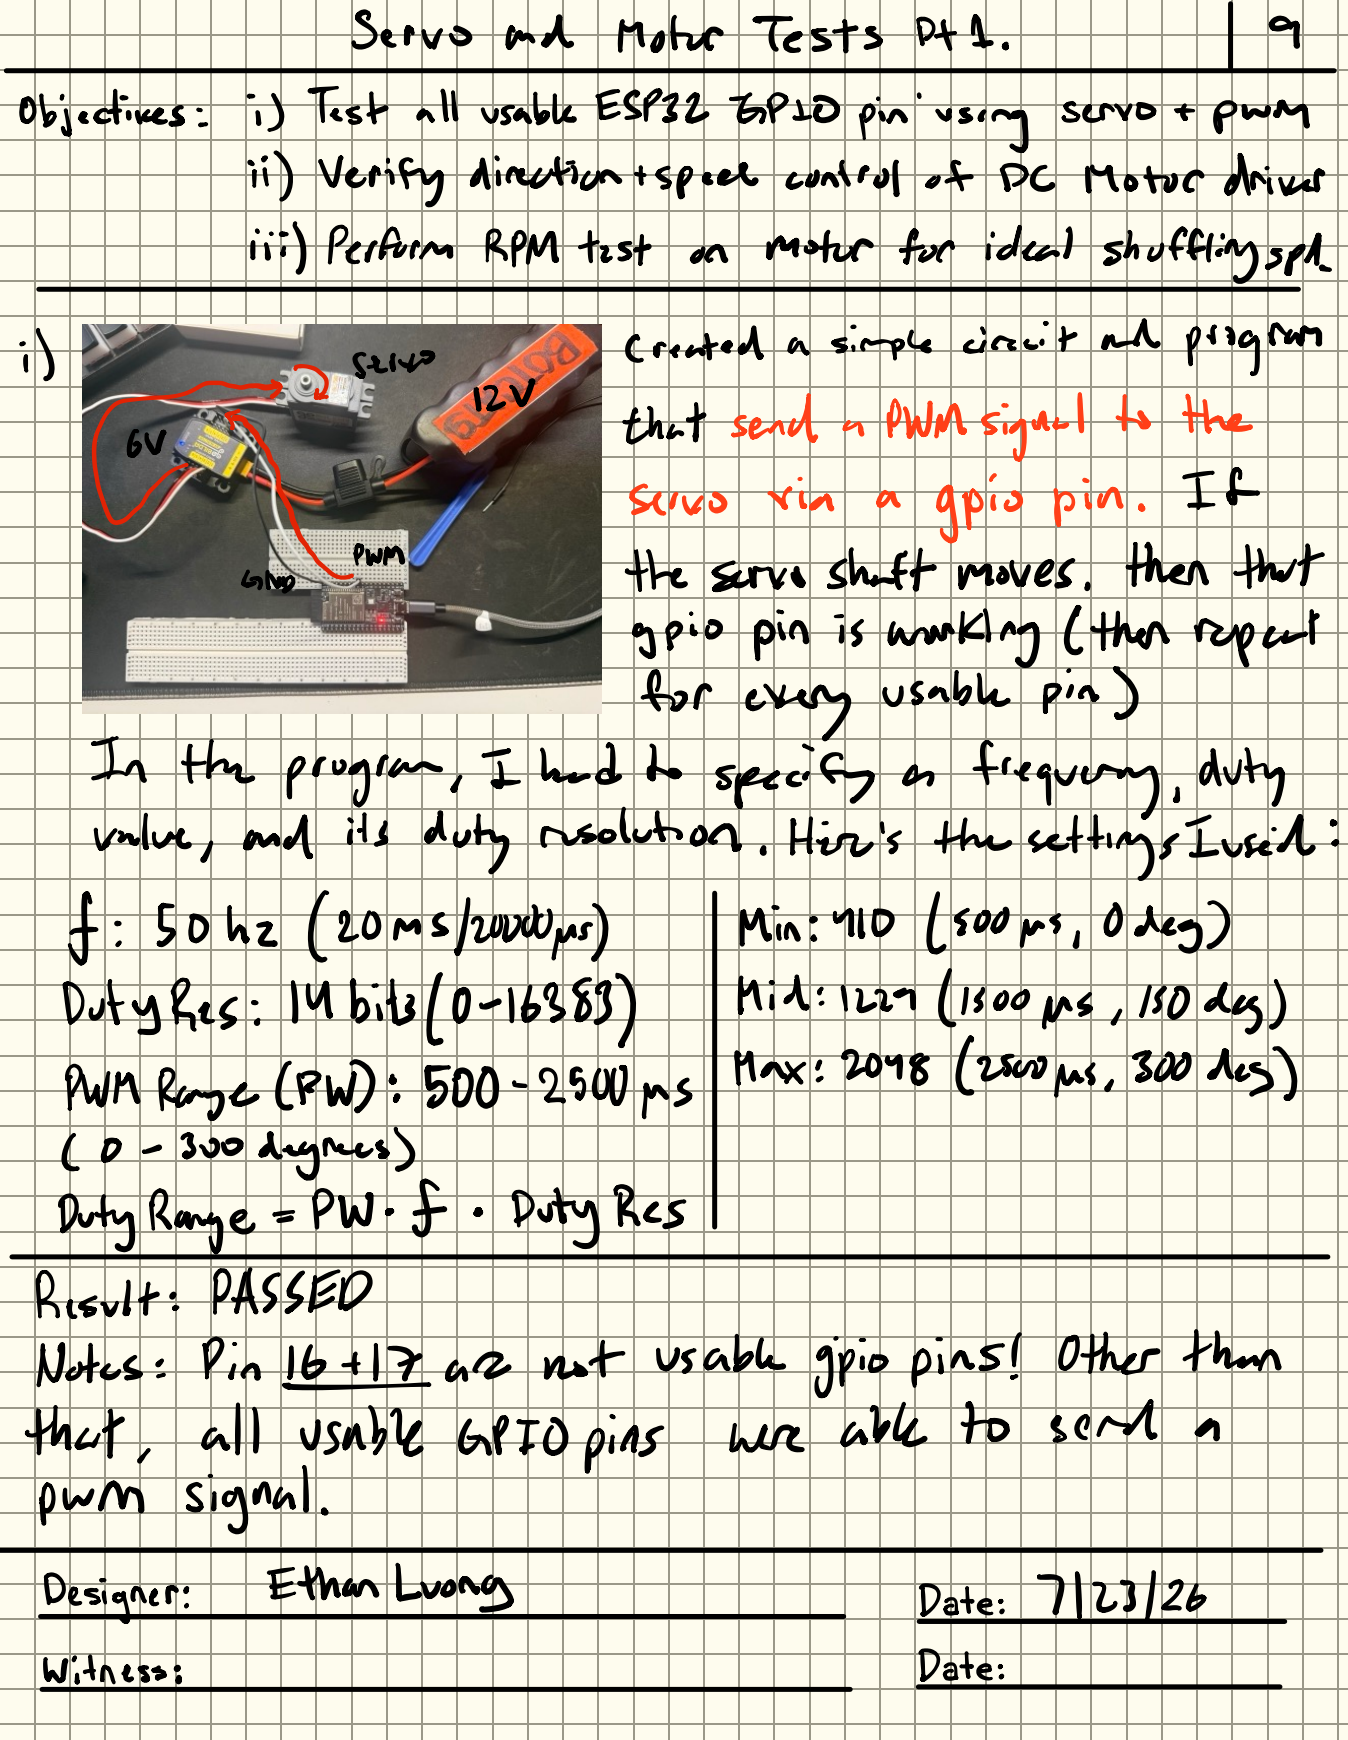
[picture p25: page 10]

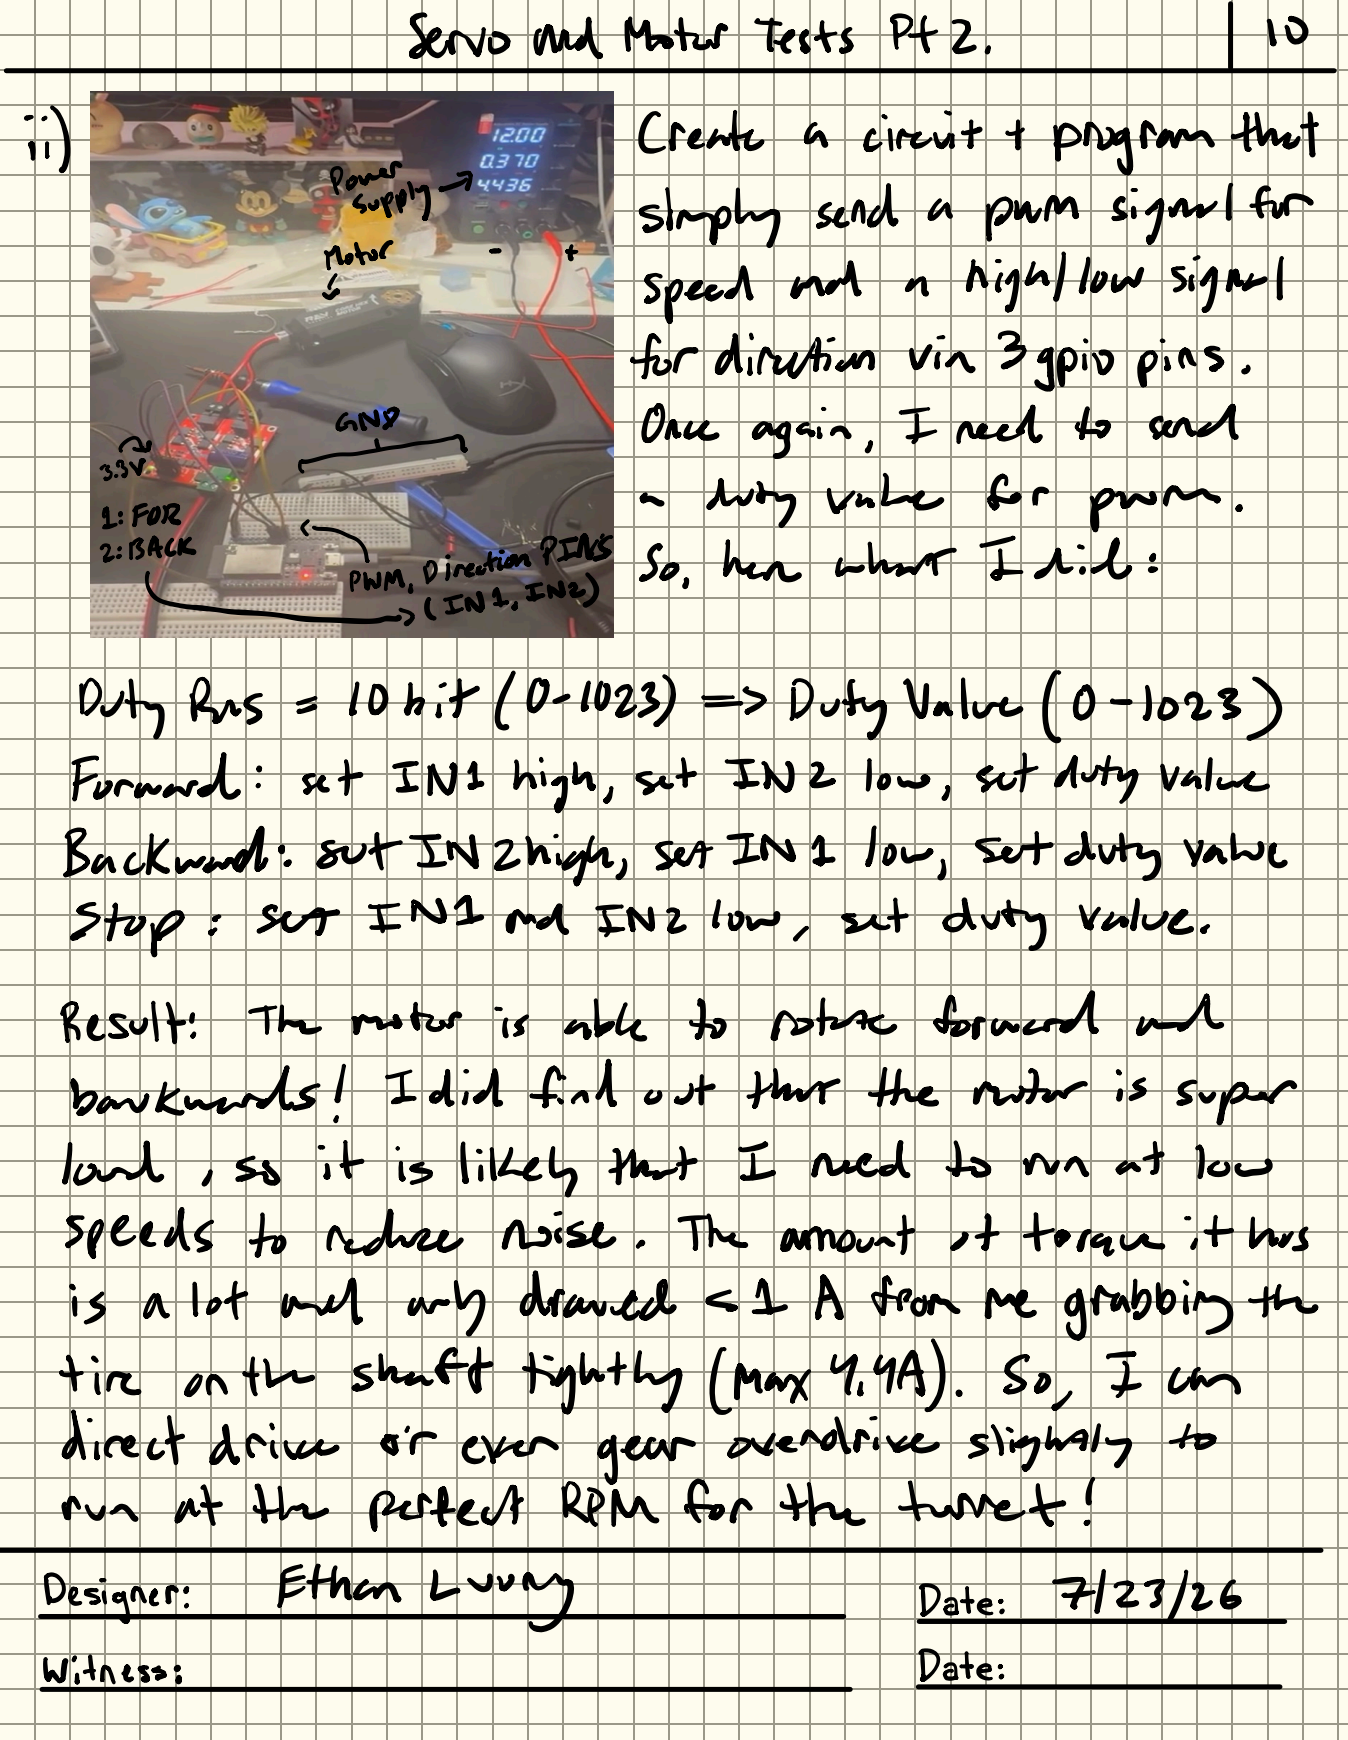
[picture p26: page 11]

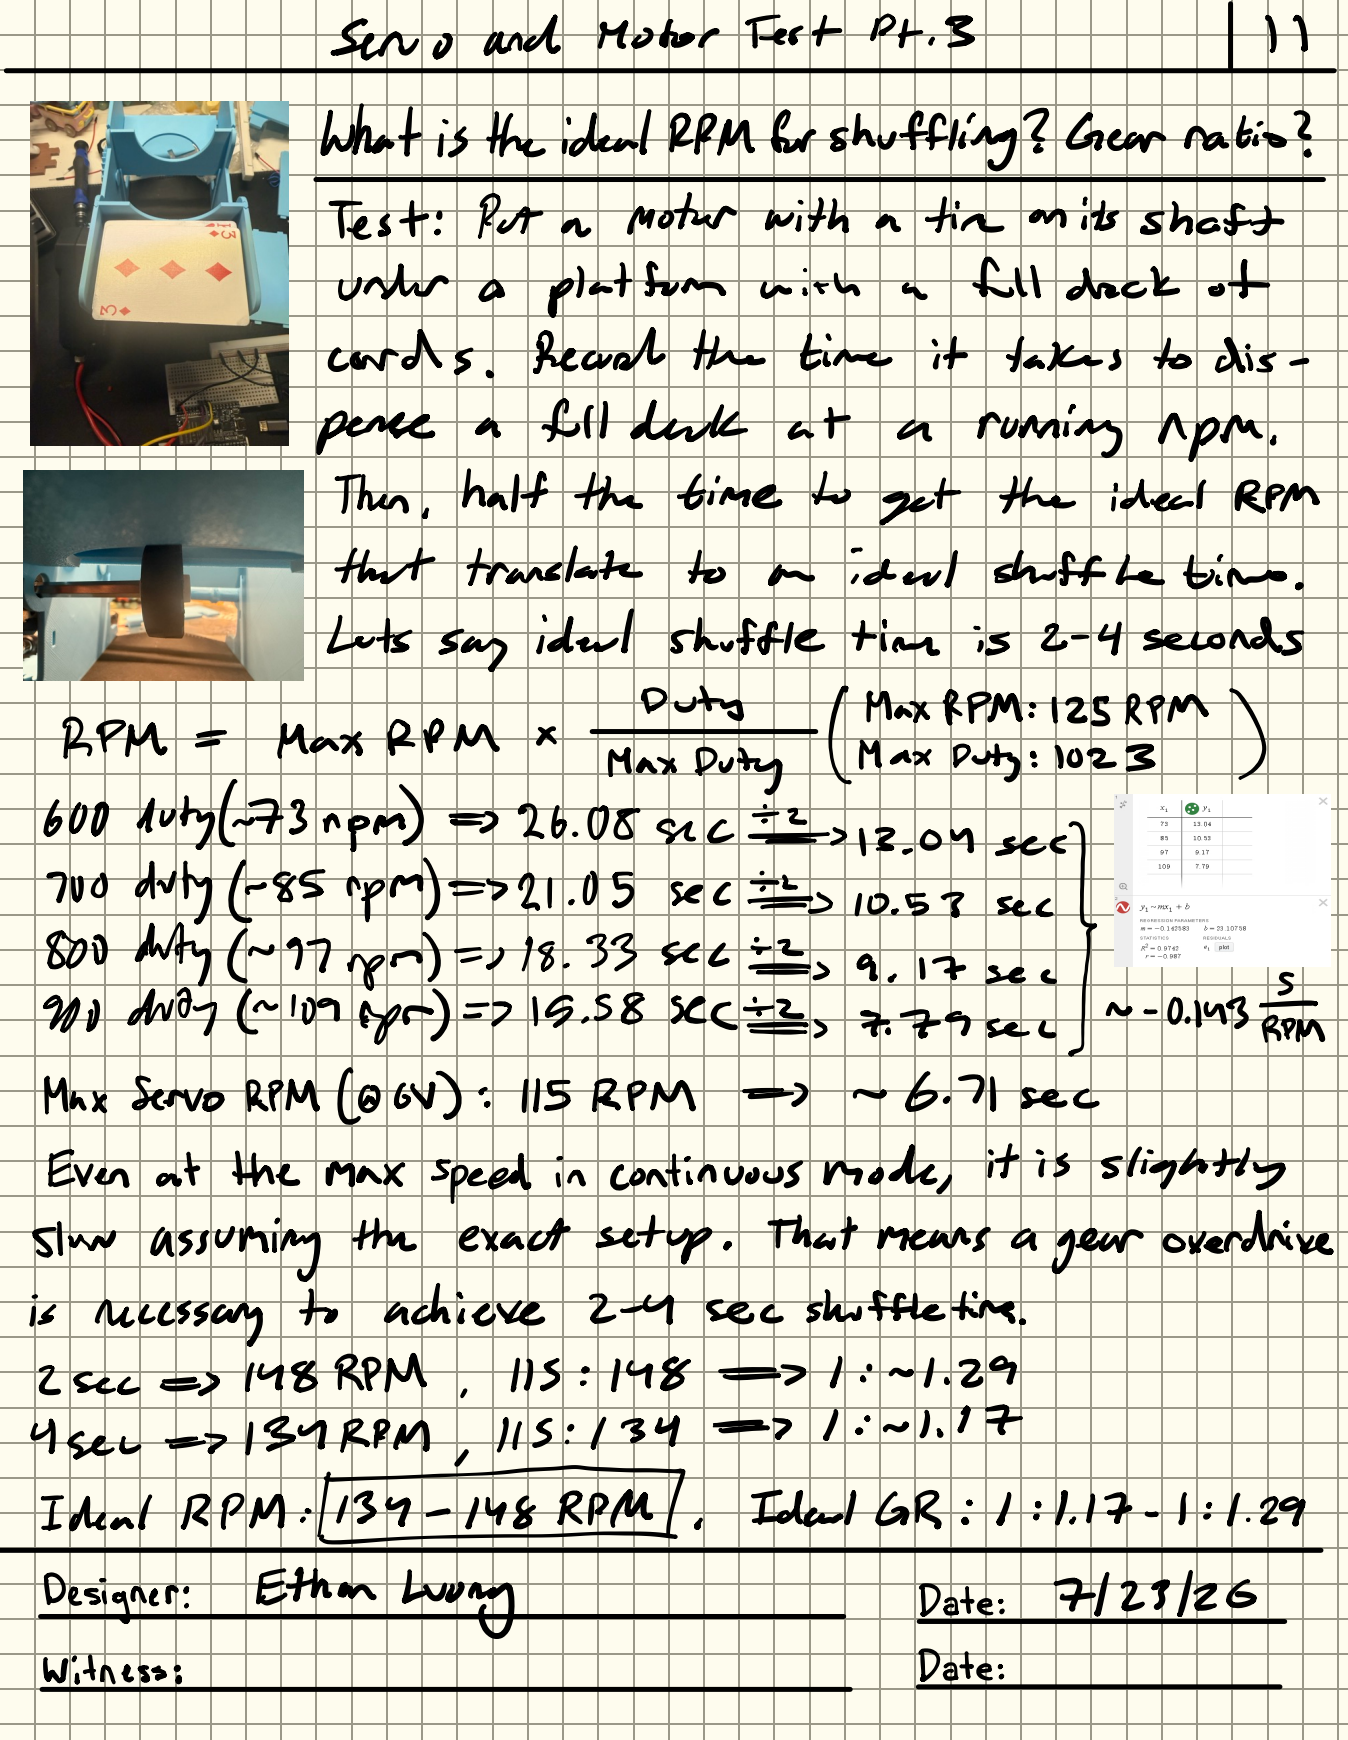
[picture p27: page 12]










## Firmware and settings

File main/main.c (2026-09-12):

#include <stdio.h>
#include <stdbool.h>

#include <freertos/FreeRTOS.h>
#include <freertos/task.h>
#include <esp_log.h>
#include <esp_timer.h>

#include <driver/gpio.h>
#include <driver/ledc.h>
#include <driver/pulse_cnt.h>
#include <driver/i2c_master.h>

#include "shuffler.h"
#include "dispenser.h"
#include "turret.h"
#include "menu.h"
#include "system_commands.h"

#define LEDC_MODE LEDC_HIGH_SPEED_MODE
static bool end_program = false;

void init_hardware() {
    init_shuffler();
    init_dispenser();
    init_turret();
    init_menu();
}

void stop(void) {
    ledc_stop(LEDC_MODE, LEDC_CHANNEL_0, 0);    
    ledc_stop(LEDC_MODE, LEDC_CHANNEL_1, 0);  
    ledc_stop(LEDC_MODE, LEDC_CHANNEL_2, 0);
    ledc_stop(LEDC_MODE, LEDC_CHANNEL_3, 0);    
}

void app_main(void)
{
    init_hardware();
    lcd_init_sequence();

    xTaskCreatePinnedToCore(turret_pid_task, "turret pid", 4096, (void *)(uintptr_t)(INITIAL_POSITION), 3, NULL, 1);
    xTaskCreatePinnedToCore(command_system_task, "command system", 4096, NULL, 2, &xSequencerTaskHandle, 1);
    xTaskCreatePinnedToCore(menu_ui_task, "menu ui task", 4096, NULL, 4, NULL, 1);

    start_button_timer();

    vTaskDelete(NULL);
}

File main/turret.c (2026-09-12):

#include <stdio.h>
#include "freertos/FreeRTOS.h"
#include "freertos/task.h"
#include "driver/gpio.h"
#include "driver/ledc.h"
#include "driver/pulse_cnt.h"

#define GPIO_PWM_ENA                        GPIO_NUM_19
#define GPIO_DIR_IN1                        GPIO_NUM_18
#define GPIO_DIR_IN2                        GPIO_NUM_5
#define GPIO_ENC_A                          GPIO_NUM_34
#define GPIO_ENC_B                          GPIO_NUM_35

#define LEDC_MODE             LEDC_HIGH_SPEED_MODE
#define MOTOR_LEDC_DUTY_RES   LEDC_TIMER_10_BIT // Duty cycle range: 0 - 1023
#define MOTOR_LEDC_FREQUENCY  (10000)

#define KP              (100)
#define KI              (0)
#define KD              (0)

static pcnt_unit_handle_t motor_pcnt_unit = NULL;
static volatile int TARGET_POSITION = 0;
const int INITIAL_POSITION = 0;

void init_motor(void) {
    // 1. Configure Direction Pins (GPIO output)
    gpio_config_t io_conf = {
        .pin_bit_mask = (1ULL << GPIO_DIR_IN1) | (1ULL << GPIO_DIR_IN2),
        .mode = GPIO_MODE_OUTPUT,
        .pull_up_en = GPIO_PULLUP_DISABLE,
        .pull_down_en = GPIO_PULLDOWN_DISABLE,
        .intr_type = GPIO_INTR_DISABLE
    };
    gpio_config(&io_conf);

    // 2. Configure LEDC Timer for PWM
    ledc_timer_config_t motor_ledc_timer = {
        .speed_mode       = LEDC_MODE,
        .timer_num        = LEDC_TIMER_1,
        .duty_resolution  = MOTOR_LEDC_DUTY_RES,
        .freq_hz          = MOTOR_LEDC_FREQUENCY,
        .clk_cfg          = LEDC_AUTO_CLK
    };
    ledc_timer_config(&motor_ledc_timer);

    // 3. Configure LEDC Channel for ENA PWM Output
    ledc_channel_config_t ledc_channel3 = {
        .speed_mode     = LEDC_MODE,
        .channel        = LEDC_CHANNEL_3,
        .timer_sel      = LEDC_TIMER_1,
        .intr_type      = LEDC_INTR_DISABLE,
        .gpio_num       = GPIO_PWM_ENA,
        .duty           = 0, // Initial duty 0 (off)
        .hpoint         = 0
    };
    ledc_channel_config(&ledc_channel3);
}

void init_motor_encoder(void) {
    // 1. Setup PCNT Unit
    pcnt_unit_config_t unit_config = {
        .low_limit = -32768,
        .high_limit = 32767,
    };
    ESP_ERROR_CHECK(pcnt_new_unit(&unit_config, &motor_pcnt_unit));

    // 2. Setup Glitch Filter (Ignores noise spikes under 1 microsecond)
    pcnt_glitch_filter_config_t filter_config = {
        .max_glitch_ns = 1000,
    };
    ESP_ERROR_CHECK(pcnt_unit_set_glitch_filter(motor_pcnt_unit, &filter_config));

    // 3. Setup Channel A (Pulse input = Channel A, Control input = Channel B)
    pcnt_chan_config_t chan_a_config = {
        .edge_gpio_num = GPIO_ENC_A,
        .level_gpio_num = GPIO_ENC_B,
    };
    pcnt_channel_handle_t pcnt_chan_a = NULL;
    ESP_ERROR_CHECK(pcnt_new_channel(motor_pcnt_unit, &chan_a_config, &pcnt_chan_a));

    // 4. Setup Channel B (Pulse input = Channel B, Control input = Channel A)
    pcnt_chan_config_t chan_b_config = {
        .edge_gpio_num = GPIO_ENC_B,
        .level_gpio_num = GPIO_ENC_A,
    };
    pcnt_channel_handle_t pcnt_chan_b = NULL;
    ESP_ERROR_CHECK(pcnt_new_channel(motor_pcnt_unit, &chan_b_config, &pcnt_chan_b));

    // 5. Define Quadrature Counting Rules (1x / 4x resolution based on edge transitions)
    ESP_ERROR_CHECK(pcnt_channel_set_edge_action(pcnt_chan_a, PCNT_CHANNEL_EDGE_ACTION_INCREASE, PCNT_CHANNEL_EDGE_ACTION_DECREASE));
    ESP_ERROR_CHECK(pcnt_channel_set_level_action(pcnt_chan_a, PCNT_CHANNEL_LEVEL_ACTION_KEEP, PCNT_CHANNEL_LEVEL_ACTION_INVERSE));

    ESP_ERROR_CHECK(pcnt_channel_set_edge_action(pcnt_chan_b, PCNT_CHANNEL_EDGE_ACTION_INCREASE, PCNT_CHANNEL_EDGE_ACTION_DECREASE));
    ESP_ERROR_CHECK(pcnt_channel_set_level_action(pcnt_chan_b, PCNT_CHANNEL_LEVEL_ACTION_INVERSE, PCNT_CHANNEL_LEVEL_ACTION_KEEP));

    // 6. Enable and Start the Counter
    ESP_ERROR_CHECK(pcnt_unit_enable(motor_pcnt_unit));
    ESP_ERROR_CHECK(pcnt_unit_clear_count(motor_pcnt_unit));
    ESP_ERROR_CHECK(pcnt_unit_start(motor_pcnt_unit));
}

void init_turret(void) {
    init_motor();
    init_motor_encoder();
}

int get_encoder_count(void)
{
    int pulse_count = 0;
    if (motor_pcnt_unit != NULL) {
        pcnt_unit_get_count(motor_pcnt_unit, &pulse_count);
    }
    return pulse_count;
}

// Set motor speed (0 to 1023)
void set_motor_speed(uint32_t duty)
{
    ledc_set_duty(LEDC_MODE, LEDC_CHANNEL_3, duty);
    ledc_update_duty(LEDC_MODE, LEDC_CHANNEL_3);
}

// Direction Control Functions
void motor_forward(uint32_t speed_duty)
{
    gpio_set_level(GPIO_DIR_IN1, 1);
    gpio_set_level(GPIO_DIR_IN2, 0);
    set_motor_speed(speed_duty);
}

void motor_backward(uint32_t speed_duty)
{
    gpio_set_level(GPIO_DIR_IN1, 0);
    gpio_set_level(GPIO_DIR_IN2, 1);
    set_motor_speed(speed_duty);
}

void motor_stop(void)
{
    gpio_set_level(GPIO_DIR_IN1, 0);
    gpio_set_level(GPIO_DIR_IN2, 0);
    set_motor_speed(0);
}

void set_motor_speed_and_direction(int32_t duty) {
    if (duty > 0) {
        gpio_set_level(GPIO_DIR_IN1, 1);
        gpio_set_level(GPIO_DIR_IN2, 0);
    }
    else if (duty < 0) {
        gpio_set_level(GPIO_DIR_IN1, 0);
        gpio_set_level(GPIO_DIR_IN2, 1);
        duty = duty * -1;
    }
    else {
        gpio_set_level(GPIO_DIR_IN1, 0);
        gpio_set_level(GPIO_DIR_IN2, 0);
    }
    set_motor_speed(duty);
}

void encoder_logger_task(void *pvParameters)
{
    while (1) {
        printf("Encoder Ticks: %d\n", get_encoder_count());
        vTaskDelay(pdMS_TO_TICKS(200)); // Print count every 200ms
    }
}

int clamp(int input, int min, int max) { // within min and max range
    if (input > max) return max;
    else if (input < min) return min;
    else return input; 
}

float pid_compute(int target, int current, float *integral_accum, int *prev_error) {
    int error = target - current;

    // Proportional term
    float p_out = KP * (float)error;

    // Integral term
    *integral_accum += (float)error;
    float i_out = KI * (*integral_accum);

    // Derivative term
    float derivative = (float)(error - *prev_error);
    float d_out = KD * derivative;

    // Store previous error for next iteration
    *prev_error = error;

    // Calculate total output
    float total_output = p_out + i_out + d_out;

    // Clamp total output to PWM limits
    int clamped_output = clamp((int)total_output, -512, 512);

    return (float)clamped_output;
}
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

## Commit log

2026-07-27 v1 dispenser CAD files upload, tested dispenser via updated servo test code
    [card-dispenser-chassis.step, card-dispenser-chassis.stl, card-dispenser-shaft.step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]
2026-07-28 dispenser v2 cad files and testing
    [card-dispenser-chassis.step, card-dispenser-chassis.stl, card-dispenser-shaft.step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]
2026-07-31 card shuffler v1 cad files and test code
    [card-shuffler-driven-gears.step, card-shuffler-driven-gears.stl, card-shuffler-driver-gears.step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]
2026-08-17 v4 shuffler cad files, PID motor test code, updated engineering notebook entries up to 8/17
    [card-shuffler-driven-gears.step, card-shuffler-driven-gears.stl, card-shuffler-driver-gears.step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]
2026-09-12 v1 card shuffler & dealer machine CAD files and source code, updated master schematic, documentation updated until 9/12/26
    [card-dispenser-chassis.step, card-dispenser-chassis.stl, card-dispenser-middle-gears.step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]
